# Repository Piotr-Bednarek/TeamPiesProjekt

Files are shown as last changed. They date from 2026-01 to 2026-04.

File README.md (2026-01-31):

<div align="center">

# Ball on Beam

</div>

## O projekcie

Celem projektu było stworzenie systemu automatycznego balansowania kulki na belce z wykorzystaniem sterowania automatycznego. Wykorzystano:

- **Regulator PID**
- **Czujnik odległości** VL53L0X
- **Serwomechanizm** do pochylania belki
- **Aplikację desktopową** do wizualizacji i strojenia parametrów

## Konstrukcja oraz aplikacja desktopowa

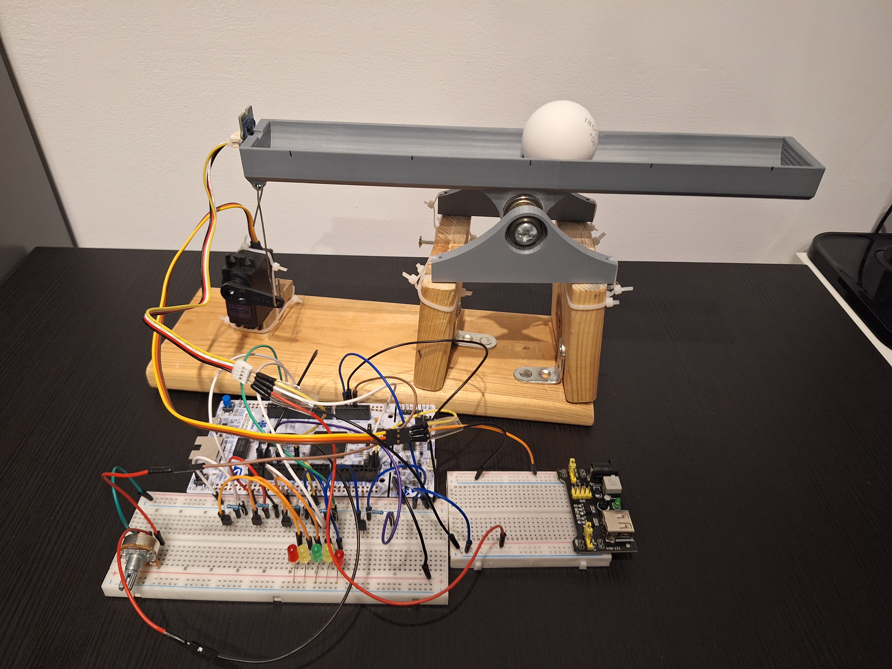
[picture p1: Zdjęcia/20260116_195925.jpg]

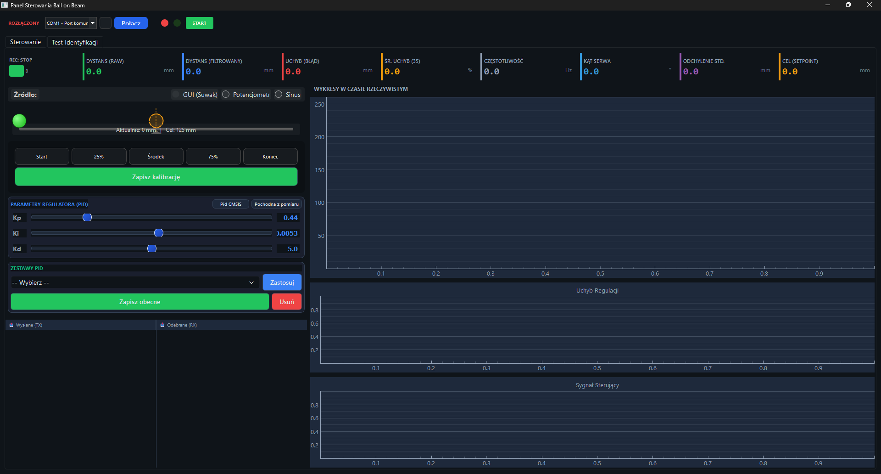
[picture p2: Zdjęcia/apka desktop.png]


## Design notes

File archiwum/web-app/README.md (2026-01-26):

# Aplikacja Webowa - STM32 Control

Nowoczesna aplikacja webowa napisana w React (Vite) do sterowania i wizualizacji danych z urządzenia STM32. Zastępuje poprzednią wersję desktopową (Python/Tkinter).

## Funkcje

-   **Połączenie Serial (Web Serial API)**: Bezpośrednie połączenie z portem COM z przeglądarki.
-   **Wizualizacja Real-time**: Wykresy odległości, błedu i sterowania.
-   **Panel Sterowania**: Zmiana parametrów PID i Setpoint na żywo.
-   **Terminal**: Podgląd logów TX/RX.
-   **Nowoczesny UI**: Ciemny motyw, responsywny layout.

## Uruchomienie

1. Zainstaluj zależności:
    ```bash
    npm install
    ```
2. Uruchom serwer developerski:
    ```bash
    npm run dev
    ```
3. Otwórz w przeglądarce (np. Chrome/Edge) adres wyświetlony w terminalu (zazwyczaj `http://localhost:5173`).

## Użycie

1. Kliknij **Connect Device** w prawym górnym rogu.
2. Wybierz port COM urządzenia STM32 z listy.
3. Dane zaczną pojawiać się na wykresach automatycznie.
4. Użyj suwaków by zmieniać `Setpoint` lub parametry `PID`.

**Uwaga**: Upewnij się, że inne aplikacje (np. stara aplikacja Python) nie blokują portu przed połączeniem.

-   [@vitejs/plugin-react-swc](https://github.com/vitejs/vite-plugin-react/blob/main/packages/plugin-react-swc) uses [SWC](https://swc.rs/) for Fast Refresh

## React Compiler

The React Compiler is not enabled on this template because of its impact on dev & build performances. To add it, see [this documentation](https://react.dev/learn/react-compiler/installation).

## Expanding the ESLint configuration

If you are developing a production application, we recommend using TypeScript with type-aware lint rules enabled. Check out the [TS template](https://github.com/vitejs/vite/tree/main/packages/create-vite/template-react-ts) for information on how to integrate TypeScript and [`typescript-eslint`](https://typescript-eslint.io) in your project.

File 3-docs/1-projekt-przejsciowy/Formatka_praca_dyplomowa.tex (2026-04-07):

% Preambuła: definicja klasy dokumentu i lista potrzebnych pakietów ///////////////////////////////////////////////////////////////////////////////////////////////////////

\documentclass[12pt, a4paper]{report} % rozmiar czcionki, klasa dokumentu
\usepackage[left=2.5cm, right=2.5cm, top=3.5cm, bottom=3.5cm]{geometry} % ustawienia marginesów
\usepackage{amsmath} % przydatne przy pisaniu wzorów i symboli matematycznych
\usepackage{amssymb} % j.w.
\usepackage{amsthm} % j.w.
\usepackage{polski} % język polski i skład tekstu zgodnie z polskimi zasadami typografii
\usepackage[T1]{fontenc} % polskie fonty w formacie wektorowym
\usepackage[utf8]{inputenc} % j.w.
\usepackage{enumerate} % konfiguracja wyglądu wypunktowań (i) (ii) A) B) 1) 2) etc.
\usepackage[pdftex]{graphicx} % umieszczanie grafiki w pracy (w tym również w formacie wektorowym PDF)
\usepackage{indentfirst} % wcięcie pierwszego akapitu
\usepackage{booktabs} % do rysowania eleganckich tabel
\usepackage{color} % kolor w LaTeXu
\usepackage{pgfplots} % rysowanie wykresów i grafiki wektorowej
\pgfplotsset{compat=1.18}
\usepackage{titlesec} % zmiana wyglądu tytułów rozdziałów (czcionka, odległości między wierszami tytułów etc.)
\usepackage[position=t,justification=centering, singlelinecheck=off]{subfig} % pozwala umieszczać rysunki obok siebie; etykiety (a) (b) etc. nad rysunkiem i wycentrowane
\usepackage{fancyhdr} % formatowanie nagłówka, stopki i żywej paginy
\usepackage{microtype} % optymalne (wizualnie) odstępy między znakami - poprawia czytelność tekstu
\usepackage[pdftex]{hyperref} % tworzenie połączeń hipertekstowych (odnośników)
\usepackage{lmodern}
\usepackage{float}    % umożliwia [H] dla figur
\usepackage{caption}  % formatowanie podpisów
\usepackage{listings} % listingi kodu źródłowego
\usepackage{xcolor}   % kolory dla listingów

% Kolory i style listingów kodu
\definecolor{codegreen}{rgb}{0,0.6,0}
\definecolor{codegray}{rgb}{0.5,0.5,0.5}
\definecolor{codepurple}{rgb}{0.58,0,0.82}
\definecolor{backcolour}{rgb}{0.95,0.95,0.92}
\definecolor{codeblue}{rgb}{0,0,0.7}

\lstdefinestyle{cstyle}{
    backgroundcolor=\color{backcolour},
    commentstyle=\color{codegreen},
    keywordstyle=\color{codeblue}\bfseries,
    numberstyle=\tiny\color{codegray},
    stringstyle=\color{codepurple},
    basicstyle=\ttfamily\footnotesize,
    breaklines=true,
    captionpos=b,
    keepspaces=true,
    numbers=left,
    numbersep=5pt,
    showstringspaces=false,
    tabsize=2,
    language=C,
    frame=single,
    rulecolor=\color{codegray},
    literate={ą}{{\k{a}}}1 {ć}{{\'c}}1 {ę}{{\k{e}}}1 {ł}{{\l{}}}1
             {ń}{{\'n}}1 {ó}{{\'o}}1 {ś}{{\'s}}1 {ź}{{\'z}}1 {ż}{{\.z}}1
             {Ą}{{\k{A}}}1 {Ć}{{\'C}}1 {Ę}{{\k{E}}}1 {Ł}{{\L{}}}1
             {Ń}{{\'N}}1 {Ó}{{\'O}}1 {Ś}{{\'S}}1 {Ź}{{\'Z}}1 {Ż}{{\.Z}}1
}

\lstdefinestyle{pythonstyle}{
    backgroundcolor=\color{backcolour},
    commentstyle=\color{codegreen},
    keywordstyle=\color{codeblue}\bfseries,
    numberstyle=\tiny\color{codegray},
    stringstyle=\color{codepurple},
    basicstyle=\ttfamily\footnotesize,
    breaklines=true,
    captionpos=b,
    keepspaces=true,
    numbers=left,
    numbersep=5pt,
    showstringspaces=false,
    tabsize=2,
    language=Python,
    frame=single,
    rulecolor=\color{codegray},
    literate={ą}{{\k{a}}}1 {ć}{{\'c}}1 {ę}{{\k{e}}}1 {ł}{{\l{}}}1
             {ń}{{\'n}}1 {ó}{{\'o}}1 {ś}{{\'s}}1 {ź}{{\'z}}1 {ż}{{\.z}}1
             {Ą}{{\k{A}}}1 {Ć}{{\'C}}1 {Ę}{{\k{E}}}1 {Ł}{{\L{}}}1
             {Ń}{{\'N}}1 {Ó}{{\'O}}1 {Ś}{{\'S}}1 {Ź}{{\'Z}}1 {Ż}{{\.Z}}1
}

% Konfiguracja nagłówka, stopki (w tym wyglądu i sposobu numeracji stron) i wyglądu tytułów głównych rozdziałów ///////////////////////////////////////////////

\pagestyle{fancy}
\cfoot{\thepage}
\fancyhead{} % czyści wszystkie pola w nagłówku
\fancyhead[RO,LE]{\textit {\textsl{Projekt i budowa układu regulacji dla układu Ball on Beam} \ldots}} % tekst w nagłówku
\fancyfoot{} % czyści wszystkie pola w stopce
\fancyfoot[C]{\thepage} % numery stron w stopce; wycentrowane

\titleformat{\chapter}[display]
  {\normalfont\Large\raggedleft}
  {\MakeUppercase{\chaptertitlename}
    \rlap{ \resizebox{!}{1.5cm}{\thechapter} \rule{5cm}{1.5cm}}}
  {10pt}{\Huge}
\titlespacing*{\chapter}{0pt}{30pt}{50pt} % odstępy w tytule głównym

% Początek dokumenty ///////////////////////////////////////////////////////////////////////////////////////////////////////////////////////////////////////////////////////////////
\begin{document}

  % Strona tytułowa
\begin{titlepage}

\vspace*{-2cm} % odstęp pionowy

\begin{center} % wypośrodkuj
\Large \textbf{POLITECHNIKA POZNAŃSKA}\\[1mm]
\Large {WYDZIAŁ AUTOMATYKI, ROBOTYKI I ELEKTROTECHNIKI}\\[1mm]
\begin{large}
Instytut Robotyki i Inteligencji Maszynowej\\[1mm]
Zakład Automatyki i Optymalizacji\\[1cm]
\end{large}
\end{center}

\begin{center}

\end{center}

\vspace{1cm}

\begin{center}
\Large \textbf {Jan Andrzejewski \\ Mateusz Banaszak \\ Piotr Bednarek}
\end{center}

\vspace{1cm}

\begin{center}
\Large \textbf{\textit{PROJEKT I BUDOWA UKŁADU REGULACJI DLA UKŁADU BALL ON BEAM}}
\end{center}

\vspace{3cm}
\hfill
\textbf {Promotor}: dr inż. Jacek Michalski

\vspace{2cm}

 \hspace*{-1cm}
\begin{minipage}{7cm}
\centering
Pracę przyjmuję i akceptuję\\

\vspace{0.5cm}

................................................\\

\textit{\footnotesize data i podpis opiekuna pracy}
\end{minipage}

\vspace{2.5cm}

\begin{center}
Poznań, \the\year
\end{center}

  % Pusta strona  (w tym miejscu karta tematu z Dziekanatu) \\\\\\\\\\\\\\\\\\\\\\\\\\\\\\\\\\\\\\\\\\\\\\\\\\\\\\\\\\\\\\\\\\\\\\\\\\\\\\\\\\\\\\\\\\\\\\\\\\\\\\\\\\\\\\\\\\
\newpage\null\thispagestyle{empty}\newpage

 % Streszczenie \\\\\\\\\\\\\\\\\\\\\\\\\\\\\\\\\\\\\\\\\\\\\\\\\\\\\\\\\\\\\\\\\\\\\\\\\\\\\\\\\\\\\\\\\\\\\\\\\\\\\\\\\\\\\\\\\\\\\\\\\\\\\\\\\\\\\\\\\\\\\\\\\\\\\\\\\\\\\\\\\\\\\\\
    \newpage\thispagestyle{empty}
    \vspace*{2\baselineskip}
    \begin{center}
	{\large\bfseries Streszczenie}\par\bigskip
    \end{center}

    {\itshape
    Praca przedstawia projekt i~budowę autonomicznego stanowiska do sterowania
    pozycją kulki na belce (\textit{ball and beam}) z~wykorzystaniem mikrokontrolera
    STM32F767ZI.
    Opisano budowę mechaniczną stanowiska, zastosowane peryferia (serwomechanek
    MG946R, czujnik odległości VL53L0X, rząd diod LED, potencjometr) oraz
    architekturę oprogramowania opartą na systemie FreeRTOS.
    Wyprowadzono model matematyczny układu i~zaprojektowano dwa regulatory:
    klasyczny PID z~anti-windup oraz optymalny LQR w~przestrzeni stanów.
    Aplikacja nadzorcza napisana w~Pythonie (PySide6) umożliwia wizualizację
    sygnałów w~czasie rzeczywistym, zapis danych do pliku CSV oraz zdalne
    strojenie regulatora.
    Przeprowadzono weryfikację eksperymentalną i~potwierdzono spełnienie
    wszystkich wymagań projektowych.
    }
    \vspace*{1\baselineskip}

    \noindent{\bf Słowa kluczowe}: {\itshape regulacja automatyczna, kulka na belce,
    STM32, PID, LQR, FreeRTOS, VL53L0X.}
    \par
    \vspace{4\baselineskip}

  % Abstract \\\\\\\\\\\\\\\\\\\\\\\\\\\\\\\\\\\\\\\\\\\\\\\\\\\\\\\\\\\\\\\\\\\\\\\\\\\\\\\\\\\\\\\\\\\\\\\\\\\\\\\\\\\\\\\\\\\\\\\\\\\\\\\\\\\\\\\\\\\\\\\\\\\\\\\\\\\\\\\\\\\\\\\\\\\
    \begin{center}
	{\large\bfseries Abstract}\par\bigskip
    \end{center}
    \noindent{\bf Title}: {\itshape Design and Construction of a Control System for the Ball and Beam System.}\par
    \vspace*{1\baselineskip}
    {\itshape
    This thesis presents the design and construction of an autonomous ball-and-beam
    control system based on the STM32F767ZI microcontroller.
    The mechanical setup, hardware peripherals (MG946R servo, VL53L0X time-of-flight
    sensor, LED bar, potentiometer), and FreeRTOS-based software architecture are
    described.
    A mathematical model of the plant is derived and two controllers are designed:
    a classical PID with anti-windup and an optimal LQR state-feedback controller.
    A supervisory desktop application (Python/PySide6) provides real-time signal
    visualisation, CSV data logging, and remote parameter tuning.
    Experimental verification confirms that all project requirements are satisfied.
    }
    \vspace*{1\baselineskip}

    \noindent{\bf Key words}: {\itshape automatic control, ball and beam, STM32, PID,
    LQR, FreeRTOS, VL53L0X.}

\end{titlepage}

  % Spis treści ]\\\\\\\\\\\\\\\\\\\\\\\\\\\\\\\\\\\\\\\\\\\\\\\\\\\\\\\\\\\\\\\\\\\\\\\\\\\\\\\\\\\\\\\\\\\\\\\\\\\\\\\\\\\\\\\\\\\\\\\\\\\\\\\\\\\\\\\\\\\\\\\\\\\\\\\\\\\\\\\\\\\\\\\\\

\tableofcontents % wstawia spis treści

 % Główna część pracy \\\\\\\\\\\\\\\\\\\\\\\\\\\\\\\\\\\\\\\\\\\\\\\\\\\\\\\\\\\\\\\\\\\\\\\\\\\\\\\\\\\\\\\\\\\\\\\\\\\\\\\\\\\\\\\\\\\\\\\\\\\\\\\\\\\\\\\\\\\\\\\\\\\

% ROZDZIAŁ 1 _________________________________________________________________________________________________________________
\input{1-wprowadzenie/1-wprowadzenie}

% ROZDZIAŁ 2 _________________________________________________________________________________________________________________
\input{2-budowa-stanowiska-i-oprogramowanie/2-budowa-stanowiska-i-oprogramowanie}

% ROZDZIAŁ 3 _________________________________________________________________________________________________________________
\input{3-model-matematyczny-i-projekt-regulacji/3-model-matematyczny-i-projekt-regulacji}

% ROZDZIAŁ 4 _________________________________________________________________________________________________________________
\input{4-wyniki-eksperymentalne/4-wyniki-eksperymentalne}

% ROZDZIAŁ 5 _________________________________________________________________________________________________________________
\input{5-podsumowanie-i-wnioski/5-podsumowanie-i-wnioski}

% BIBLIOGRAFIA ___________________________________________________________________________________________________________
\bibliographystyle{unsrt} % kolejność cytowania w tekście
\bibliography{bibliografia}

\listoffigures
\appendix

\end{document}

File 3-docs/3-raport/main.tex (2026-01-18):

\documentclass[11pt]{article}

\pdfobjcompresslevel=3    % compress PDF objects
\pdfcompresslevel=9       % compress streams more (0..9)
\pdfminorversion=4

\usepackage[utf8]{inputenc} % remove if using XeLaTeX or LuaLaTeX
\usepackage[T1]{fontenc}
\usepackage{polski}[babel]

% Layout & graphics
\usepackage[a4paper, total={7.5in, 9in}]{geometry}
\usepackage{graphicx}
\usepackage{wrapfig}              % images
\usepackage[dvipsnames,table]{xcolor} % single xcolor invocation (keeps table option)

% Math & symbols
\usepackage{amsmath}
\usepackage{amssymb}
\usepackage{gensymb}

% Typography & layout helpers
\usepackage{microtype}
\usepackage{float}                 % [H] placement
\usepackage{caption}
\usepackage{subcaption}            % modern subfigure support (do NOT load subfig)
\usepackage{multirow}
\usepackage{titlesec}

\usepackage{lmodern}
\usepackage{listings}
\usepackage{xcolor}

\geometry{margin=2.5cm}

% Kolory dla listingow kodu
\definecolor{codegreen}{rgb}{0,0.6,0}
\definecolor{codegray}{rgb}{0.5,0.5,0.5}
\definecolor{codepurple}{rgb}{0.58,0,0.82}
\definecolor{backcolour}{rgb}{0.95,0.95,0.92}
\definecolor{codeblue}{rgb}{0,0,0.7}

\definecolor{xppblue}{RGB}{37, 150, 190}

% Styl dla kodu C
\lstdefinestyle{cstyle}{
    backgroundcolor=\color{backcolour},   
    commentstyle=\color{codegreen},
    keywordstyle=\color{codeblue}\bfseries,
    numberstyle=\tiny\color{codegray},
    stringstyle=\color{codepurple},
    basicstyle=\ttfamily\footnotesize,
    breakatwhitespace=false,         
    breaklines=true,                 
    captionpos=b,                    
    keepspaces=true,                 
    numbers=left,                    
    numbersep=5pt,                  
    showspaces=false,                
    showstringspaces=false,
    showtabs=false,                  
    tabsize=2,
    language=C,
    frame=single,
    rulecolor=\color{codegray},
    literate={ą}{{\k{a}}}1 {ć}{{\'c}}1 {ę}{{\k{e}}}1 {ł}{{\l{}}}1 {ń}{{\'n}}1 {ó}{{\'o}}1 {ś}{{\'s}}1 {ź}{{\'z}}1 {ż}{{\.z}}1
             {Ą}{{\k{A}}}1 {Ć}{{\'C}}1 {Ę}{{\k{E}}}1 {Ł}{{\L{}}}1 {Ń}{{\'N}}1 {Ó}{{\'O}}1 {Ś}{{\'S}}1 {Ź}{{\'Z}}1 {Ż}{{\.Z}}1
}

% Styl dla kodu Python
\lstdefinestyle{pythonstyle}{
    backgroundcolor=\color{backcolour},   
    commentstyle=\color{codegreen},
    keywordstyle=\color{codeblue}\bfseries,
    numberstyle=\tiny\color{codegray},
    stringstyle=\color{codepurple},
    basicstyle=\ttfamily\footnotesize,
    breakatwhitespace=false,         
    breaklines=true,                 
    captionpos=b,                    
    keepspaces=true,                 
    numbers=left,                    
    numbersep=5pt,                  
    showspaces=false,                
    showstringspaces=false,
    showtabs=false,                  
    tabsize=2,
    language=Python,
    frame=single,
    rulecolor=\color{codegray},
    literate={ą}{{\k{a}}}1 {ć}{{\'c}}1 {ę}{{\k{e}}}1 {ł}{{\l{}}}1 {ń}{{\'n}}1 {ó}{{\'o}}1 {ś}{{\'s}}1 {ź}{{\'z}}1 {ż}{{\.z}}1
             {Ą}{{\k{A}}}1 {Ć}{{\'C}}1 {Ę}{{\k{E}}}1 {Ł}{{\L{}}}1 {Ń}{{\'N}}1 {Ó}{{\'O}}1 {Ś}{{\'S}}1 {Ź}{{\'Z}}1 {Ż}{{\.Z}}1
}

\lstset{style=cstyle}

\begin{document}

\begin
{table}[H]
\centering
\begin
{tabular}{|p{4cm}|p{8cm}|p{2cm}|}
\hline
\multicolumn{2}{|c|}{\cellcolor{xppblue}\textcolor[rgb]{1,1,1}{Politechnika Poznańska}}  & \multicolumn{1}{c|}{\multirow{3}{*}{\resizebox{14mm}{!}{}}}\\
\multicolumn{2}{|c|}{\cellcolor{xppblue}\textcolor[rgb]{1,1,1}{Wydział Automatyki, Robotyki i Elektrotechniki}} & \\
\multicolumn{2}{|c|}{\cellcolor{xppblue}\textcolor[rgb]{1,1,1}{Instytut Robotyki i Inteligencji Maszynowej}} & \\
\hline
\multicolumn{1}{|c|}{AiR Sem 5} & \multicolumn{1}{c|}{Systemy mikroprocesorowe} & \multicolumn{1}{c|}{2025/26 (s.zim.)} \\
\hline
Jan Andrzejewski \par Mateusz Banaszak \par Piotr Bednarek & \textbf{Raport z projektu zaliczeniowego} \par Ball on Beam & Data wyk.:\par 18.01.2026\\
\hline
Grupa środa 13:30  & &  \\
\hline
\end{tabular}
\end{table}

\tableofcontents
\newpage

\section{Wprowadzenie}
\subsection{Zakres i cel projektu}

Za cel projektu obrano zbudowanie stanowiska służacego do sterowania obiektem dynamiczym "Ball on beam". Za cel przy implementacji zostało przyjęte spełnienie dodatkowych wymogów projektowych opisanych w następnym rozdziale. 

\begin{figure}[H]
    \centering
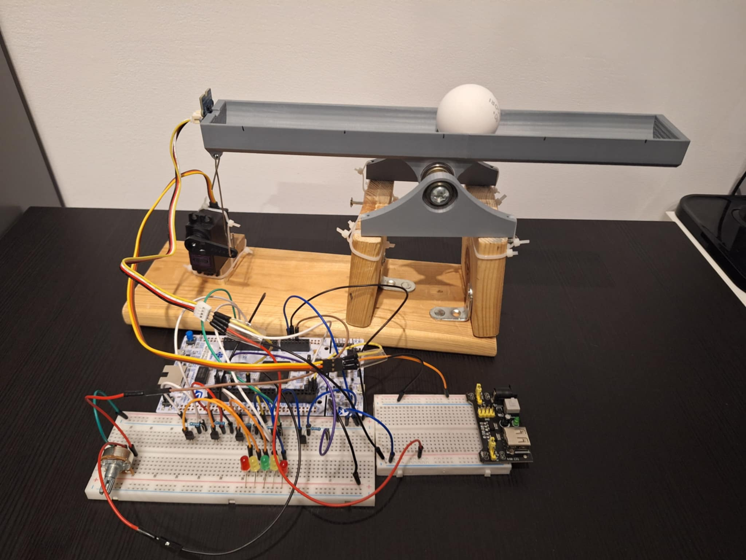
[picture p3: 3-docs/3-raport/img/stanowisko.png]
    
    \caption{Stanowisko}
\end{figure}

\begin{figure}[H]
    \centering
    
    \caption{Aplikacja desktopowa}
\end{figure}

\subsection{Wykorzystane elementy}

\begin{itemize}
    \item STM Nucleo F767ZI
    \item Servo TowerPro MG946R
    \item Grove - VL53LOX Timeof Flight I2C
    \item Diody LED - 1x zielona, 2x czerwona, 2x żółta 
    \item 5x tranzystory npn pn2222
    \item 5x rezystory 2k$\Omega$
    \item Potencjometr 
    \item Zasilacz 5 V
\end{itemize}

%%%%%%%%%%%%%%%%%%%%%%%%%%%%%%%%%%%%%%%%%%%%%%%%%%%%%%%%%%%%%%%%%%%%%%%%%%%%%%%
\section{Wymagania projektowe}
%%%%%%%%%%%%%%%%%%%%%%%%%%%%%%%%%%%%%%%%%%%%%%%%%%%%%%%%%%%%%%%%%%%%%%%%%%%%%%%

Poniżej przedstawiono wymagania projektowe, które spełnia projekt, wraz z fragmentami kodu dokumentującymi ich implementację.

%------------------------------------------------------------------------------
\subsection{Pomiar zmiennej regulowanej ze stałym okresem próbkowania}
%------------------------------------------------------------------------------

System dokonuje pomiaru regulowanej zmiennej (pozycji kulki) ze stałym okresem próbkowania zdefiniowanym jako \texttt{PID\_DT\_MS = 30ms}. Zapewnia to funkcja \texttt{osDelay()} systemu FreeRTOS wywołana na końcu pętli sterowania.

\begin{lstlisting}[caption={Stały okres próbkowania (main.h)}, style=cstyle]
// --- Global System Settings ---
#define PID_DT_MS          30
#define SETPOINT_DEFAULT   125.0f
#define BALL_RADIUS        20
#define AVG_ERR_SAMPLES    35
\end{lstlisting}

\begin{lstlisting}[caption={Implementacja stałego okresu w pętli sterowania (main.c)}, style=cstyle]
/* Infinite loop */
for (;;) {
    loop_counter++;
    
    // ... kod sterowania ...
    
    // Odczyt dystansu w trybie continuous
    distance = readRangeContinuousMillimeters(&distanceStr);
    
    // ... obliczenia PID ...
    
    osDelay(PID_DT_MS); // Loop delay - staly okres 30ms
}
\end{lstlisting}

%------------------------------------------------------------------------------
\subsection{Sterowanie w bezpiecznym zakresie zmian regulowanej zmiennej}
%------------------------------------------------------------------------------

System zapewnia bezpieczne sterowanie poprzez zdefiniowanie twardych limitów kąta serwa w pliku \texttt{main.h} oraz ich egzekwowanie w kodzie sterowania.

\begin{lstlisting}[caption={Definicje limitów bezpieczeństwa serwa (main.h)}, style=cstyle]
// --- Servo Configuration ---
#define SERVO_CENTER       100.0f
#define SERVO_MIN_LIMIT    60.0f
#define SERVO_MAX_LIMIT    140.0f
#define SERVO_ANGLE_DEADBAND 0.8f
\end{lstlisting}

\begin{lstlisting}[caption={Saturacja wyjścia PID (main.c)}, style=cstyle]
// Zabezpieczenie przed NaN (Not a Number)
if (isnan(pid_angle) || isinf(pid_angle)) {
    pid_angle = SERVO_CENTER;
}

if (pid_angle < SERVO_MIN_LIMIT)
    pid_angle = SERVO_MIN_LIMIT;
else if (pid_angle > SERVO_MAX_LIMIT)
    pid_angle = SERVO_MAX_LIMIT;

// Bezposrednie sterowanie serwem
volatile float smoothed_angle = pid_angle;
SetServoAngle(smoothed_angle);
\end{lstlisting}

\newpage

%------------------------------------------------------------------------------
\subsection{Uchyb ustalony na poziomie 5\% (i 1\%) zakresu regulacji}
%------------------------------------------------------------------------------

System oblicza średni błąd (rolling average) z ostatnich 35 próbek, co pozwala na monitorowanie uchybu ustalonego. Zakres regulacji wynosi 250 mm, więc 5\% = 12,5 mm, a 1\% = 2,5 mm.

Wartość średniego uchybu jest przesyłana przez UART i wyświetlana w czasie rzeczywistym w aplikacji desktopowej na panelu metryk oraz na wykresie. Umożliwia to bieżącą ocenę jakości regulacji bez konieczności analizy surowych danych.

\begin{lstlisting}[caption={Obliczenie uchybu z 35 (main.c)}, style=cstyle]
// --- Obliczanie Średniego Błędu (Rolling Average) ---
		float current_abs_err = (current_error < 0) ? -current_error : current_error;
		
		err_sum -= err_buffer[err_idx];       // Odejmij najstarszą próbkę
		err_buffer[err_idx] = current_abs_err; // Zapisz nową
		err_sum += current_abs_err;           // Dodaj nową próbkę
		
		err_idx++;
		if(err_idx >= AVG_ERR_SAMPLES) err_idx = 0;
		
		float avg_error = err_sum / AVG_ERR_SAMPLES;
\end{lstlisting}

%------------------------------------------------------------------------------
\subsection{Zadawanie wartości referencyjnej za pomocą komunikacji szeregowej lub urządzenia wejścia}
%------------------------------------------------------------------------------

Wartość referencyjna może być zadawana na dwa sposoby:
\begin{itemize}
    \item Przez komunikację szeregową UART (komenda \texttt{S:wartosc})
    \item Przez potencjometr podłączony do wejścia ADC (PA0)
\end{itemize}

\begin{lstlisting}[caption={Obsługa komendy setpointu przez UART (main.c)}, style=cstyle]
void StartDefaultTask(void const * argument) {
    for (;;) {
        // Obsluga komend UART
        if (cmd_received) {
            if (rx_buffer[0] == 'S' && rx_buffer[1] == ':') {
                g_setpoint = atof((char*) &rx_buffer[2]); // S:Setpoint
                if (g_setpoint < 0.0f)
                    g_setpoint = 0.0f;
                if (g_setpoint > 250.0f)
                    g_setpoint = 250.0f;
            }
            // ... inne komendy ...
            cmd_received = 0;
        }
        osDelay(5);
    }
}
\end{lstlisting}

\begin{lstlisting}[caption={Odczyt setpointu z potencjometru ADC (main.c)}, style=cstyle]
// --- Obsluga Potencjometru ---
HAL_ADC_Start(&hadc1);
if (HAL_ADC_PollForConversion(&hadc1, 10) == HAL_OK) {
    g_adc_raw = HAL_ADC_GetValue(&hadc1);
    float pot_setpoint = (float)g_adc_raw * 0.070818f; 
    g_pot_setpoint = pot_setpoint; 
    
    // Jeśli tryb Analog, nadpisz setpoint
    if (control_mode == 1) {
        // Lekki filtr na setpoint z potencjometru
        static float pot_ema = 0.0f;
        if (pot_ema == 0.0f) pot_ema = pot_setpoint;
        pot_ema = 0.1f * pot_setpoint + 0.9f * pot_ema;
        g_setpoint = pot_ema;
    }
}
HAL_ADC_Stop(&hadc1);
\end{lstlisting}

%------------------------------------------------------------------------------
\subsection{Podgląd sygnałów przez komunikację szeregową}
%------------------------------------------------------------------------------

System wysyła dane pomiarowe przez UART w formacie tekstowym z sumą kontrolną CRC-8. Dane zawierają: dystans surowy (D), setpoint (Z), kąt serwa (A), dystans filtrowany (F), błąd (E), średni błąd (V) oraz status sensora (S).

\begin{lstlisting}[caption={Wysyłanie danych przez UART z CRC (main.c)}, style=cstyle]
char data_buffer[64];
// D:Dist (raw); A:Angle; F:Filtered; E:Error; V:AvgError; S:Status; Z:Setpoint
int len = sprintf(data_buffer, "D:%d;Z:%d;A:%d;F:%d;E:%d;V:%d;S:%d", 
    (int)raw_distance, (int)g_setpoint, (int)smoothed_angle, 
    (int)filtered_dist, (int)current_error, (int)avg_error, 
    distanceStr.rangeStatus);

uint8_t out_crc = CalculateCRC8(data_buffer, len);

sprintf(msg, "%s;C:%02X\r\n", data_buffer, out_crc);
static uint8_t u_throttle = 0;
if (++u_throttle >= 2) {
    u_throttle = 0;
    HAL_UART_Transmit(&huart3, (uint8_t*) msg, strlen(msg), 10);
}
\end{lstlisting}

%------------------------------------------------------------------------------
\subsection{Podział kodu na moduły i dokumentacja Doxygen}
%------------------------------------------------------------------------------

Kod źródłowy jest podzielony na osobne moduły o jasno zdefiniowanych funkcjonalnościach. Każdy moduł posiada dokumentację zgodną ze standardem Doxygen.

\textbf{Struktura modułów STM32:}
\begin{itemize}
    \item \texttt{main.c/h} -- główna aplikacja, konfiguracja peryferiów
    \item \texttt{pid.c/h} -- wrapper na CMSIS DSP PID
    \item \texttt{servo\_pid.c/h} -- własna implementacja PID z Anti-Windup
    \item \texttt{filters.c/h} -- filtry cyfrowe (Mediana, EMA, 1-Euro)
    \item \texttt{crc8.c/h} -- obliczanie sumy kontrolnej CRC-8
    \item \texttt{leds.c/h} -- wizualizacja błędu na LEDach
    \item \texttt{calibration.c/h} -- kalibracja sensora
\end{itemize}

\begin{lstlisting}[caption={Przykład dokumentacji Doxygen (pid.c)}, style=cstyle]
/**
 ******************************************************************************
 * @file    pid.c
 * @author  Piotr Bednarek Jan Andrzejewski Mateusz Banaszak
 * @date    Jan 8, 2026
 * @brief   Wrapper na biblioteke CMSIS DSP PID.
 *
 * Plik zawiera funkcje inicjalizujace i obslugujace regulator PID
 * z wykorzystaniem zoptymalizowanej biblioteki matematycznej ARM (CMSIS DSP).
 ******************************************************************************
 */

/**
 * @brief Inicjalizuje regulator PID.
 *        Ustawia wspolczynniki wzmocnienia oraz limity wyjscia (nasycenie).
 *        Wywoluje arm_pid_init_f32 aby zresetowac stan wewnetrzny algorytmu.
 * @param pid Wskaznik do struktury PID_Controller_t.
 * @param Kp Wzmocnienie proporcjonalne.
 * @param Ki Wzmocnienie calkujace.
 * @param Kd Wzmocnienie rozniczkujace.
 * @param min_out Dolny limit wyjscia.
 * @param max_out Gorny limit wyjscia.
 */
void PID_Init(PID_Controller_t *pid, float Kp, float Ki, float Kd, 
              float min_out, float max_out) {
    // ...
}
\end{lstlisting}

%------------------------------------------------------------------------------
\subsection{Wykorzystanie systemu kontroli wersji}
%------------------------------------------------------------------------------

Projekt wykorzystuje system kontroli wersji Git. Repozytorium znajduje sie w katalogu glownym projektu (\texttt{.git/}).

%------------------------------------------------------------------------------
\subsection{Dedykowana aplikacja desktopowa (GUI)}
%------------------------------------------------------------------------------

Aplikacja desktopowa została napisana w języku Python z wykorzystaniem frameworka PySide6 (Qt). Umożliwia ona:
\begin{itemize}
    \item Połączenie z mikrokontrolerem przez port szeregowy
    \item Wizualizację sygnałów w czasie rzeczywistym (wykresy PyQtGraph)
    \item Wybór trybu (UI, sinus, śledzenie trajektorii) i zadawanie sygnału referencyjnego 
    \item Zadawanie wartości parametrów PID
    \item Nagrywanie i eksport sygnałów do CSV
    \item Sterowanie trybem pracy regulatora (Start/Stop)
\end{itemize}

\begin{lstlisting}[caption={Główna klasa aplikacji GUI (app.py)}, style=pythonstyle]
from PySide6.QtWidgets import QMainWindow, QWidget, QVBoxLayout, QHBoxLayout
from serial_manager import SerialManager
from widgets.metrics_panel import MetricsPanel
from widgets.control_panel import ControlPanel
from widgets.charts_panel import ChartsPanel
from widgets.terminal import Terminal

class MainWindow(QMainWindow):
    def __init__(self):
        super().__init__()
        
        self.setWindowTitle("Panel Sterowania Ball on Beam")
        self.resize(1280, 800)
        
        # --- Managers ---
        self.serial = SerialManager()
        self.data_history = []
        
        # --- Recording State ---
        self.is_recording = False
        self.recording_data = []
        
        # ... konfiguracja UI ...
\end{lstlisting}

\begin{lstlisting}[caption={Manager komunikacji szeregowej (serial\_manager.py)}, style=pythonstyle]
class SerialManager(QObject):
    """
    High-level manager for Serial communication. 
    Handles Thread management, Parsing, and Signal emission.
    """
    # Signals for UI
    connected = Signal(bool)
    rx_log = Signal(str, str)  # msg, type (info/error/success)
    tx_log = Signal(str)
    new_data = Signal(dict)    # Parsed data object
    ports_listed = Signal(list)
    
    def send_setpoint(self, val):
        self.send_command(f"S:{val:.1f}")
        
    def send_pid(self, kp, ki, kd):
        self.send_pid_p(kp)
        QThread.msleep(500)
        self.send_pid_i(ki)
        QThread.msleep(500)
        self.send_pid_d(kd)
\end{lstlisting}

%------------------------------------------------------------------------------
\subsection{Skrypty do logowania sygnałów}
%------------------------------------------------------------------------------

Aplikacja desktopowa posiada wbudowany mechanizm nagrywania danych pomiarowych do plików CSV z możliwością eksportu.

\begin{lstlisting}[caption={Funkcja zapisu nagrania do CSV (app.py)}, style=pythonstyle]
def _save_recording(self):
    # Generate default filename with timestamp
    timestamp = datetime.now().strftime("%Y%m%d_%H%M%S")
    default_filename = f"nagranie_{timestamp}.csv"
    
    # Open file dialog
    filepath, _ = QFileDialog.getSaveFileName(
        self,
        "Zapisz nagranie",
        default_filename,
        "CSV Files (*.csv);;All Files (*)"
    )
    
    if filepath:
        try:
            with open(filepath, 'w', newline='', encoding='utf-8') as f:
                fieldnames = ['time', 'distance', 'filtered', 
                              'setpoint', 'error', 'control']
                writer = csv.DictWriter(f, fieldnames=fieldnames)
                writer.writeheader()
                writer.writerows(self.recording_data)
        except Exception as e:
            self.terminal.append_rx(f"Blad zapisu: {e}", "error")
\end{lstlisting}

%------------------------------------------------------------------------------
\subsection{Dodatkowe urządzenie wyjścia -- wyświetlacz LED}
%------------------------------------------------------------------------------

System posiada 5 diod LED (PE2--PE6) wizualizujących aktualny uchyb regulacji:
\begin{itemize}
    \item LED zielona (PE4) -- błąd w zakresie $\pm$1\% (2,5 mm)
    \item LEDy żółte (PE3, PE5) -- błąd w zakresie $\pm$5\% (12,5 mm)
    \item LEDy czerwone (PE2, PE6) -- błąd większy niż $\pm$5\%
\end{itemize}

\begin{lstlisting}[caption={Definicje pinow LED (main.h)}, style=cstyle]
// --- LED Error Bar ---
#define LED_ERR_PORT      GPIOE
#define LED_ERR_1_Pin     GPIO_PIN_2 //PE2
#define LED_ERR_2_Pin     GPIO_PIN_3 //PE3
#define LED_ERR_3_Pin     GPIO_PIN_4 //PE4
#define LED_ERR_4_Pin     GPIO_PIN_5 //PE5
#define LED_ERR_5_Pin     GPIO_PIN_6 //PE6
\end{lstlisting}

\begin{lstlisting}[caption={Update stanu LED (leds.c)}, style=cstyle]
void UpdateErrorLEDs_5LED(float error) {
	// Wyłącz wszystkie LEDy (PE2..PE6)
	HAL_GPIO_WritePin(GPIOE, LED_ERR_1_Pin | LED_ERR_2_Pin | LED_ERR_3_Pin | 
	                         LED_ERR_4_Pin | LED_ERR_5_Pin, GPIO_PIN_RESET);
	
	// Progi: 
	// 1% z 250mm = 2.5mm
	// 5% z 250mm = 12.5mm
	float limit_green = 2.5f;
	float limit_yellow = 12.5f;
	
	if (error < -limit_yellow) {
		// Duży ujemny -> Czerwona (PE2 - LED_ERR_1)
		HAL_GPIO_WritePin(GPIOE, LED_ERR_1_Pin, GPIO_PIN_SET);
	} else if (error < -limit_green) {
		// Średni ujemny -> Żółta (PE3 - LED_ERR_2)
		HAL_GPIO_WritePin(GPIOE, LED_ERR_2_Pin, GPIO_PIN_SET);
	} else if (error <= limit_green) { 
		// Mały błąd (+/- 2.5mm) -> Zielona (PE4 - LED_ERR_3)
		HAL_GPIO_WritePin(GPIOE, LED_ERR_3_Pin, GPIO_PIN_SET);
	} else if (error <= limit_yellow) {
		// Średni dodatni -> Żółta (PE5 - LED_ERR_4)
		HAL_GPIO_WritePin(GPIOE, LED_ERR_4_Pin, GPIO_PIN_SET);
	} else {
		// Duży dodatni -> Czerwona (PE6 - LED_ERR_5)
		HAL_GPIO_WritePin(GPIOE, LED_ERR_5_Pin, GPIO_PIN_SET);
	}
}
\end{lstlisting}

\begin{figure}[H]
    \centering
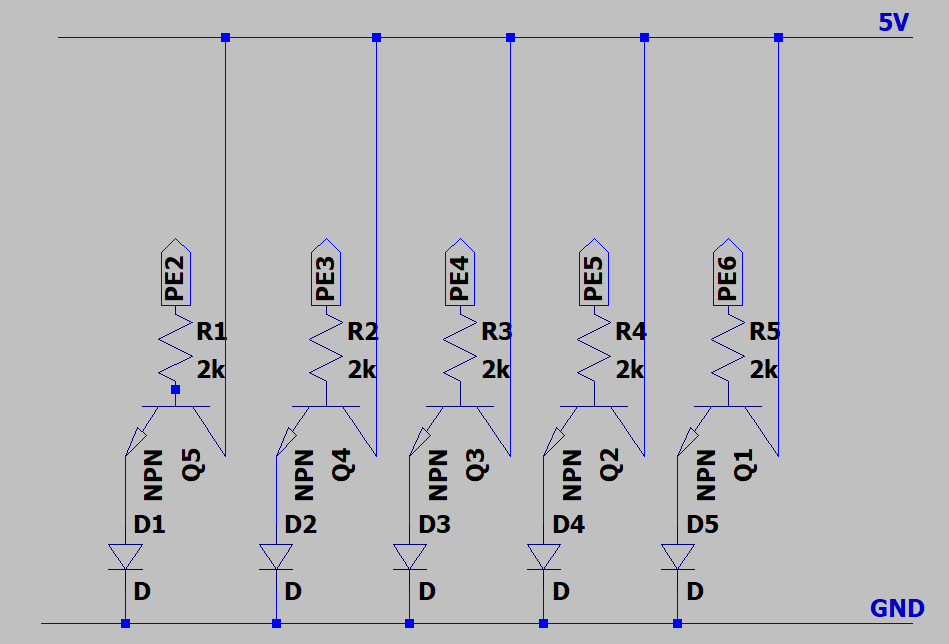
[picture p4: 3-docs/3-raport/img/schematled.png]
    
    \caption{Schemat połączenia LED}
\end{figure}

%------------------------------------------------------------------------------
\subsection{Dodatkowe urządzenie wejścia -- potencjometr}
%------------------------------------------------------------------------------

System wykorzystuje potencjometr podłączony do wejścia analogowego PA0 (ADC1\_CH0) do zadawania wartości referencyjnej w trybie analogowym.

\begin{lstlisting}[caption={Konfiguracja ADC dla potencjometru (main.c)}, style=cstyle]
static void MX_ADC1_Init(void) {
    ADC_ChannelConfTypeDef sConfig = {0};
    
    hadc1.Instance = ADC1;
    hadc1.Init.ClockPrescaler = ADC_CLOCK_SYNC_PCLK_DIV4;
    hadc1.Init.Resolution = ADC_RESOLUTION_12B;
    hadc1.Init.ScanConvMode = ADC_SCAN_DISABLE;
    hadc1.Init.ContinuousConvMode = DISABLE;
    // ...
    
    sConfig.Channel = ADC_CHANNEL_0;
    sConfig.Rank = ADC_REGULAR_RANK_1;
    sConfig.SamplingTime = ADC_SAMPLETIME_480CYCLES;
    HAL_ADC_ConfigChannel(&hadc1, &sConfig);
}
\end{lstlisting}

%------------------------------------------------------------------------------
\subsection{Protokół komunikacji z sumą kontrolną CRC-8}
%------------------------------------------------------------------------------

Komunikacja szeregowa wykorzystuje sumę kontrolną CRC-8 z wielomianem 0x07 dla zapewnienia integralności danych. Implementacja jest identyczna po stronie STM32 (C) i aplikacji desktopowej (Python).

\begin{lstlisting}[caption={Implementacja CRC-8 (crc8.c)}, style=cstyle]
/**
 * @brief Oblicza CRC-8 dla ciagu danych.
 *        Algorytm XOR z przesunieciami bitowymi.
 */
uint8_t CalculateCRC8(const char *data, int len) {
    uint8_t crc = 0x00;
    for (int i = 0; i < len; i++) {
        crc ^= data[i];
        for (uint8_t j = 0; j < 8; j++) {
            if (crc & 0x80)
                crc = (crc << 1) ^ 0x07;
            else
                crc <<= 1;
        }
    }
    return crc;
}
\end{lstlisting}

\begin{lstlisting}[caption={Implementacja CRC-8 w Pythonie (utils/crc8.py)}, style=pythonstyle]
def calculate_crc8(text: str) -> int:
    """
    Calculates 8-bit CRC for the given string using polynomial 0x07.
    Consistent with the STM32 implementation.
    """
    crc = 0x00
    if not text:
        return 0
        
    for char in text:
        byte = ord(char)
        crc ^= byte
        for _ in range(8):
            if crc & 0x80:
                crc = (crc << 1) ^ 0x07
            else:
                crc <<= 1
            crc &= 0xFF
            
    return crc
\end{lstlisting}

%------------------------------------------------------------------------------
\subsection{Wykorzystanie systemu czasu rzeczywistego FreeRTOS}
%------------------------------------------------------------------------------

System wykorzystuje FreeRTOS jako system operacyjny czasu rzeczywistego. Zdefiniowane sa dwa taski:
\begin{itemize}
    \item \texttt{ControlTask} (priorytet wysoki) -- petla sterowania PID
    \item \texttt{DefaultTask} (priorytet normalny) -- obsluga komend UART i LEDow
\end{itemize}

\begin{lstlisting}[caption={Tworzenie taskow FreeRTOS (main.c)}, style=cstyle]
/* Create the thread(s) */
/* definition and creation of defaultTask */
osThreadDef(defaultTask, StartDefaultTask, osPriorityNormal, 0, 256);
defaultTaskHandle = osThreadCreate(osThread(defaultTask), NULL);

/* definition and creation of ControlTask */
osThreadDef(ControlTask, StartControlTask, osPriorityHigh, 0, 1024);
ControlTaskHandle = osThreadCreate(osThread(ControlTask), NULL);

/* Start scheduler */
osKernelStart();
\end{lstlisting}

\begin{lstlisting}[caption={Task sterowania PID (main.c)}, style=cstyle]
/**
 * @brief Function implementing the ControlTask thread.
 * @param argument: Not used
 * @retval None
 */
void StartControlTask(void const * argument) {
    // Uruchomienie PWM dla serwa
    HAL_TIM_PWM_Start(&htim3, TIM_CHANNEL_1);
    
    // Inicjalizacja czujnika VL53L0X
    initVL53L0X(1, &hi2c1);
    startContinuous(0);
    
    // Inicjalizacja kontrolera PID
    PID_Init(&g_pid_ctrl, g_Kp, g_Ki, g_Kd, SERVO_MIN_LIMIT, SERVO_MAX_LIMIT);
    ServoPID_Init(&g_servo_pid);
    
    for (;;) {
        // Petla sterowania PID
        distance = readRangeContinuousMillimeters(&distanceStr);
        
        // ... filtrowanie i kalibracja ...
        
        // Obliczenie PID
        pid_output = ServoPID_Compute(&g_servo_pid, error, filtered_dist);
        SetServoAngle(pid_output);
        
        osDelay(PID_DT_MS);
    }
}
\end{lstlisting}

\begin{lstlisting}[caption={Konfiguracja FreeRTOS (freertos.c)}, style=cstyle]
/* Includes */
#include "FreeRTOS.h"
#include "task.h"
#include "main.h"

/* GetIdleTaskMemory prototype (linked to static allocation support) */
void vApplicationGetIdleTaskMemory(StaticTask_t **ppxIdleTaskTCBBuffer, 
                                   StackType_t **ppxIdleTaskStackBuffer, 
                                   uint32_t *pulIdleTaskStackSize);

static StaticTask_t xIdleTaskTCBBuffer;
static StackType_t xIdleStack[configMINIMAL_STACK_SIZE];

void vApplicationGetIdleTaskMemory(StaticTask_t **ppxIdleTaskTCBBuffer, 
                                   StackType_t **ppxIdleTaskStackBuffer, 
                                   uint32_t *pulIdleTaskStackSize) {
    *ppxIdleTaskTCBBuffer = &xIdleTaskTCBBuffer;
    *ppxIdleTaskStackBuffer = &xIdleStack[0];
    *pulIdleTaskStackSize = configMINIMAL_STACK_SIZE;
}
\end{lstlisting}

%%%%%%%%%%%%%%%%%%%%%%%%%%%%%%%%%%%%%%%%%%%%%%%%%%%%%%%%%%%%%%%%%%%%%%%%%%%%%%%
\section{Podsumowanie}
%%%%%%%%%%%%%%%%%%%%%%%%%%%%%%%%%%%%%%%%%%%%%%%%%%%%%%%%%%%%%%%%%%%%%%%%%%%%%%%

Projekt spełnia wszystkie wymagania funkcjonalne i dodatkowe:

\begin{enumerate}
    \item \textbf{Pomiar ze stałym okresem} -- \texttt{osDelay(PID\_DT\_MS)} zapewnia 30 ms okres próbkowania
    \item \textbf{Bezpieczny zakres sterowania} -- limity serwa 60--140 stopni
    \item \textbf{Uchyb ustalony} -- rolling average z 35 próbek, uchyb ustalony na poziomie <1\%
    \item \textbf{Zadawanie wartości referencyjnej} -- UART (komenda S:) i potencjometr (ADC PA0)
    \item \textbf{Podgląd sygnałów} -- ramki UART z danymi D/Z/A/F/E/V/S + CRC-8
    \item \textbf{Modularność i Doxygen} -- 7 modułów C, pełna dokumentacja API
    \item \textbf{Kontrola wersji} -- repozytorium Git
    \item \textbf{Aplikacja desktopowa} -- PySide6 (Qt) z wykresami PyQtGraph
    \item \textbf{Logowanie sygnałów} -- eksport do CSV z timestampami
    \item \textbf{Urządzenie wyjścia} -- 5 diod LED (PE2--PE6)
    \item \textbf{Urządzenie wejścia} -- potencjometr na ADC1\_CH0
    \item \textbf{Suma kontrolna CRC-8} -- wielomian 0x07, zgodna implementacja STM32/Python
    \item \textbf{FreeRTOS} -- 2 taski (ControlTask, DefaultTask)
\end{enumerate}

\end{document}

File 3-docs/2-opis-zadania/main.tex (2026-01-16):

\documentclass[12pt, a4paper]{article}

% Pakiety kodowania i językowe
\usepackage[utf8]{inputenc}
\usepackage[T1]{fontenc}
\usepackage[polish]{babel}

% Pakiety do geometrii i 
\usepackage{geometry}
\usepackage{graphicx}
\usepackage{float}
\usepackage{hyperref}
\usepackage{listings}
\usepackage{xcolor}

% Konfiguracja geometrii strony
\geometry{
    a4paper,
    left=25mm,
    top=25mm,
    bottom=25mm,
    right=25mm
}

% Konfiguracja linków
\hypersetup{
    colorlinks=true,
    linkcolor=black,
    filecolor=magenta,      
    urlcolor=blue,
}

% Konfiguracja wyświetlania kodu
\lstset{
    basicstyle=\ttfamily\footnotesize,
    breaklines=true,
    captionpos=b,
    frame=single,
    numbers=left,
    numberstyle=\tiny,
    keywordstyle=\color{blue},
    commentstyle=\color{green!60!black},
    stringstyle=\color{purple}
}

% Dane dokumentu
\title{Układ sterowania położeniem piłki pingpongowej na belce}
\author{Piotr Bednarek \\ Jan Andrzejewski \\ Mateusz Banaszak}
\date{\today}

\begin{document}

\maketitle

\section{Wstęp}
Przedmiotem projektu jest układ automatycznej regulacji pozycji piłki pingpongowej na
pochylonej belce. System wykorzystuje serwo TowerPro MG946R do sterowania kątem nachylenia belki
oraz laserowy czujnik odległości Time-of-Flight VL53L0X do pomiaru aktualnego położenia
piłki. Mikrokontroler STM32F767ZI analizuje dane z czujnika i w czasie rzeczywistym
koryguje nachylenie belki, aby utrzymać piłkę w zadanej pozycji lub śledzić określoną
trajektorię. Układ stanowi klasyczny przykład zastosowania regulacji PID w systemie
niestabilnym, gdzie niewielkie zakłócenia mogą prowadzić do utraty kontroli nad obiektem.

\section{Opis sprzętu}
Opis wykorzystanego mikrokontrolera (STM32) oraz peryferiów (czujniki, moduły).

\begin{itemize}
    \item STM Nucleo F767ZI
    \item Servo TowerPro MG946R
    \item Grove - VL53LOX Timeof Flight I2C
\end{itemize}

\begin{figure}[H]
    \centering
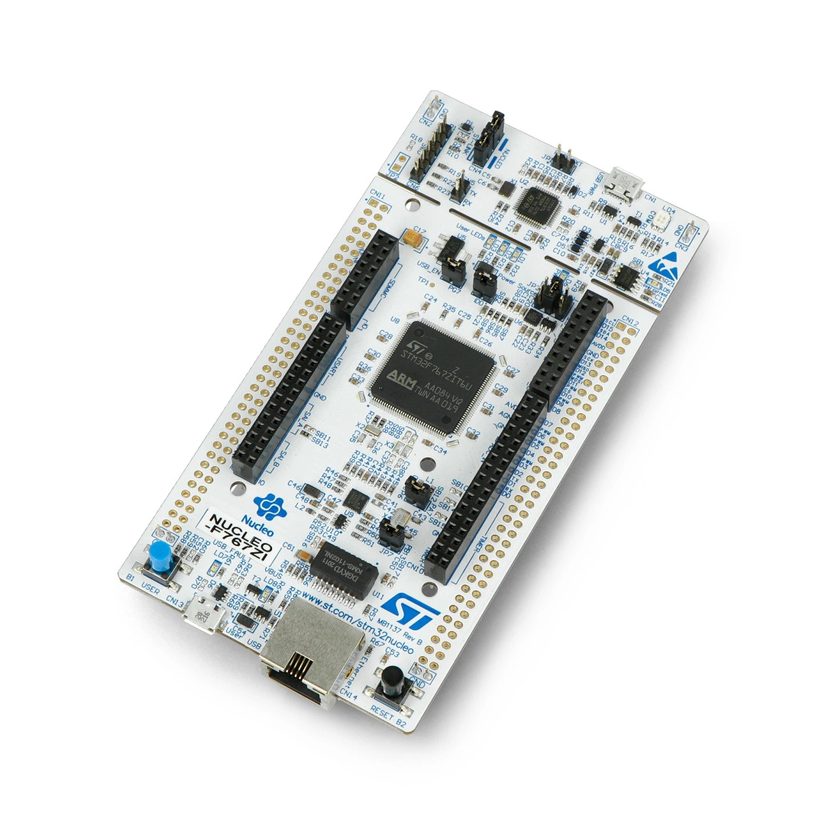
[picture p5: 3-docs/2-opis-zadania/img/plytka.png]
    
\end{figure}

\begin{figure}[H]
    \centering
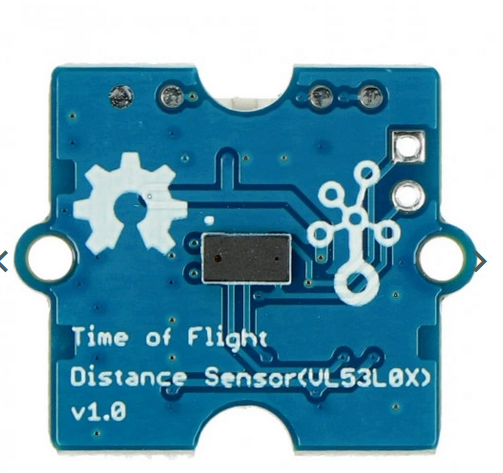
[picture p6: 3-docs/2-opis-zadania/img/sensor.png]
    
\end{figure}

\begin{figure}[H]
    \centering
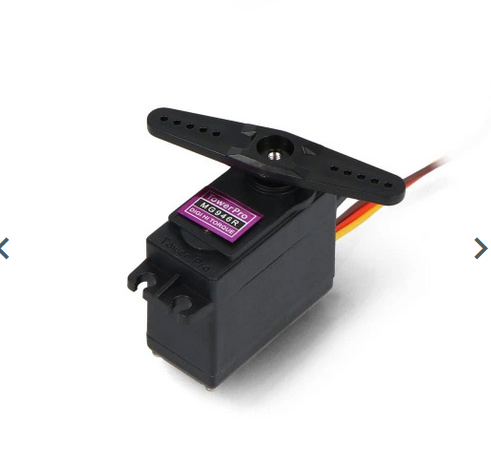
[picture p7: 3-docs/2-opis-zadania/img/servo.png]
    
\end{figure}

\section{Wymagania dodatkowe}
\begin{enumerate}
    \item Podział kodu źródłowego na moduły i dokumentacja kodu zgodna ze standardem dokumentacji.
    \item Wykorzystanie systemu kontroli wersji (Git) z publicznym repozytorium (GitHub).
    \item Dedykowana aplikacja desktopowa jako graficzny interfejs użytkownika
          zaprogramowana w Pythonie za pomocą nowoczesnych bibliotek.
          % \item Zapewnienie uchybu ustalonego na poziomie 1\% zakresu regulacji w stanie ustalonym za pomocą
          %   odpowiednio dostrojonego regulatora PID.
    \item Implementacja śledzenia sygnałów sterujących i pomiarowych za pomocą wykresów w aplikacji desktopowej (UI).
    \item Dodatkowe urządzenie wyjścia użytkownika za pomocą rzędu diod LED RGB do
          wizualizacji uchybu układu.
    \item Dodatkowe przyciski do manualnej zmiany kątu nachylenia belki lub wentylator wprowadzający
          zakłócenia do układu.
    \item Zapewnienie logow z procesu stabilizacji do odtworzenia przebiegow uchyby i wyjscia po przeprowadzeniu eksperymentu (CSV/TXT)
    \item Dodatkowe urządzenie wejścia użytkownika w postaci potencjometru do zmiany zadanej pozycji piłki na belce.
    \item Wykorzystanie sumy kontrolnej do wykrywania błędów transmisji w komunikacji szeregowej.
    \item Wykorzystanie systemu czasu rzeczywistego FreeRTOS.
\end{enumerate}

\section{Model/druk 3D}

\begin{figure}[H]
    \centering
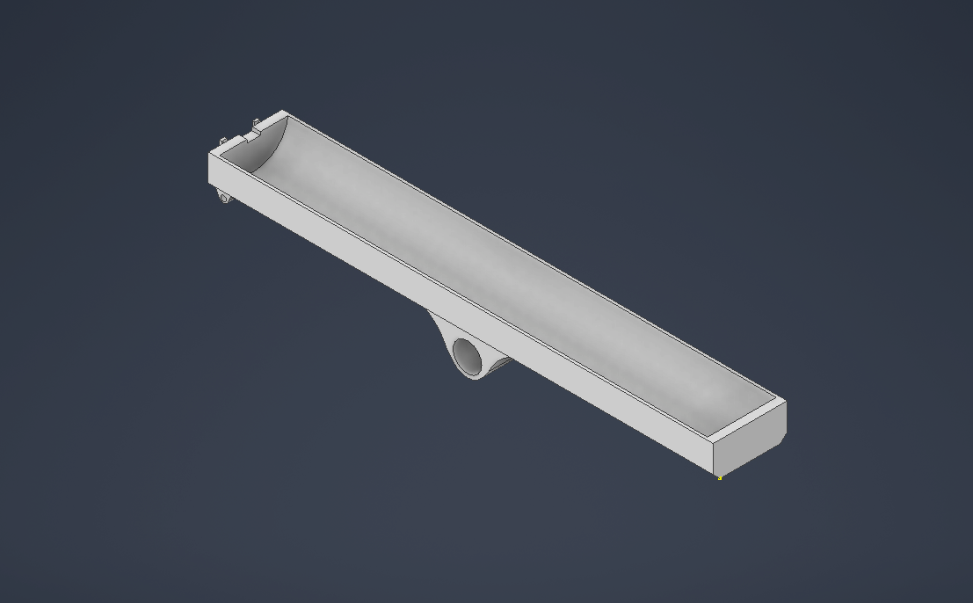
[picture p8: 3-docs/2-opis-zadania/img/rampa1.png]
    
\end{figure}

\begin{figure}[H]
    \centering
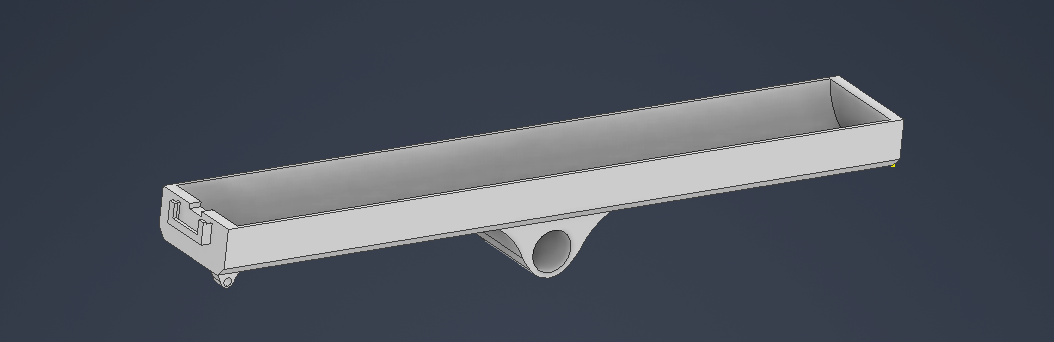
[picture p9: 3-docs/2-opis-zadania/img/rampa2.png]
    
\end{figure}

\end{document}

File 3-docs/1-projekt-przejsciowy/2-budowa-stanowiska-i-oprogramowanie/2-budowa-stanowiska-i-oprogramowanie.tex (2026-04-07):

% ROZDZIAŁ 2: Budowa stanowiska i oprogramowanie

\chapter{Budowa stanowiska i oprogramowanie}
\label{ch:budowa}

Niniejszy rozdział opisuje fizyczną budowę stanowiska laboratoryjnego, zastosowane
komponenty elektroniczne, środowisko programistyczne oraz architekturę oprogramowania
sterującego — firmware mikrokontrolera i~aplikację nadzorczą.

% -----------------------------------------------------------------------
\section{Opis stanowiska laboratoryjnego}
% -----------------------------------------------------------------------

Stanowisko składa się z~wydrukowanej w~technologii 3D pochyłej belki, po której
swobodnie toczy się metalowy walec (kulka).
Kąt nachylenia belki kontrolowany jest przez serwomechanek połączony z~belką
za pomocą dźwigni.
Pozycja kulki mierzona jest bezdotykowo za pomocą czujnika odległości ToF
zamontowanego na końcu belki.
Mikrokontroler STM32 odczytuje pomiar z~czujnika, oblicza sygnał sterujący
i~generuje odpowiedni sygnał PWM dla serwa.

\begin{figure}[H]
  \centering
  
  \caption{Stanowisko laboratoryjne układu kulka na belce}
  \label{fig:stanowisko}
\end{figure}

\subsection{Wykaz komponentów}

\begin{table}[H]
  \centering
  \caption{Komponenty sprzętowe stanowiska}
  \label{tab:komponenty}
  \begin{tabular}{lll}
    \toprule
    \textbf{Element} & \textbf{Model / opis} & \textbf{Interfejs} \\
    \midrule
    Mikrokontroler & STM32 Nucleo F767ZI & --- \\
    Serwomechanek  & TowerPro MG946R      & PWM 50\,Hz \\
    Czujnik odległości & Grove VL53L0X ToF & I\textsuperscript{2}C \\
    Potencjometr   & liniowy & ADC (PA0) \\
    Zasilacz       & 5\,V DC & --- \\
    \bottomrule
  \end{tabular}
\end{table}

% -----------------------------------------------------------------------
\section{Mikrokontroler STM32 i peryferia}
% -----------------------------------------------------------------------

\subsection{Mikrokontroler STM32F767ZI}

Głównym procesorem stanowiska jest mikrokontroler STM32F767ZI~\cite{stm32f767zi}
zamontowany na płytce ewaluacyjnej Nucleo-F767ZI.
Układ oparty jest na rdzeniu ARM Cortex-M7 taktowanym z~częstotliwością 216\,MHz
i~wyposażony jest w~bogatą gamę peryferiów: kilka interfejsów I\textsuperscript{2}C
i UART, timery sprzętowe, przetwornik ADC oraz obsługę sygnałów PWM.

\begin{figure}[H]
  \centering
  
  \caption{Płytka ewaluacyjna STM32 Nucleo-F767ZI}
\end{figure}

\subsection{Serwomechanek MG946R}

Do sterowania kątem belki zastosowano serwomechanek TowerPro MG946R.
Serwo przyjmuje sygnał PWM o~częstotliwości 50\,Hz i~czasie wypełnienia
od 1\,ms (pełne wychylenie w~jedną stronę) do 2\,ms (pełne wychylenie
w~drugą stronę).
Zakres roboczy ograniczony jest w~oprogramowaniu do 60--140° w~celu
zabezpieczenia mechaniki.

\begin{figure}[H]
  \centering
  
  \caption{Serwomechanek TowerPro MG946R}
\end{figure}

\subsection{Czujnik odległości VL53L0X}

Pozycja kulki mierzona jest czujnikiem VL53L0X~\cite{vl53l0x} firmy
STMicroelectronics, pracującym w~technologii Time-of-Flight (ToF).
Czujnik emituje krótkie impulsy laserowe podczerwieni i~mierzy czas
powrotu odbitego sygnału, co pozwala wyznaczyć odległość z~rozdzielczością
1\,mm w~zakresie do 2\,m.
Komunikacja z~mikrokontrolerem odbywa się przez magistralę I\textsuperscript{2}C.

\begin{figure}[H]
  \centering
  
  \caption{Czujnik odległości Grove VL53L0X Time-of-Flight}
\end{figure}

\subsection{Potencjometr}

Potencjometr liniowy podłączony do wejścia analogowego PA0 (ADC1\_CH0)
umożliwia ręczne zadawanie wartości referencyjnej pozycji kulki
w~trybie analogowym.
Przetwornik ADC skonfigurowany jest z~rozdzielczością 12-bitową
($0$--$4095$), co odpowiada zakresowi pozycji $0$--$250\,\mathrm{mm}$.

% -----------------------------------------------------------------------
\section{Środowisko programistyczne}
% -----------------------------------------------------------------------

\subsection{Firmware STM32}

Oprogramowanie mikrokontrolera zostało opracowane w~środowisku
STM32CubeIDE (Eclipse CDT ze zintegrowanym kompilatorem ARM GCC).
Konfigurację peryferiów (timery, I\textsuperscript{2}C, UART, ADC, PWM)
wygenerowano za pomocą narzędzia STM32CubeMX.
Kod źródłowy podzielono na osobne moduły~C zgodnie ze standardem Doxygen:

\begin{table}[H]
  \centering
  \caption{Moduły firmware}
  \label{tab:moduly}
  \begin{tabular}{ll}
    \toprule
    \textbf{Moduł} & \textbf{Opis} \\
    \midrule
    \texttt{main.c/h}       & Główna aplikacja, konfiguracja peryferiów \\
    \texttt{servo\_pid.c/h} & Regulator PID z~anti-windup \\
    \texttt{lqr.c/h}        & Regulator LQR (przestrzeń stanów) \\
    \texttt{filters.c/h}    & Filtry cyfrowe (EMA, mediana, 1-Euro) \\
    \texttt{crc8.c/h}       & Suma kontrolna CRC-8 \\
    \texttt{calibration.c/h}& Kalibracja czujnika VL53L0X \\
    \texttt{vl53l0x.c/h}    & Sterownik czujnika (I\textsuperscript{2}C) \\
    \bottomrule
  \end{tabular}
\end{table}

System operacyjny czasu rzeczywistego FreeRTOS zarządza wykonaniem dwóch
wątków (tasków):
\begin{itemize}
  \item \texttt{ControlTask} (priorytet wysoki) — pętla sterowania;
  \item \texttt{DefaultTask} (priorytet normalny) — obsługa komend UART.
\end{itemize}

\subsection{Aplikacja desktopowa}

Aplikacja nadzorcza napisana jest w~języku Python~3 z~wykorzystaniem
frameworka PySide6 (Qt~6).
Zapewnia ona:
\begin{itemize}
  \item połączenie z~mikrokontrolerem przez port szeregowy (pyserial),
  \item wizualizację sygnałów w~czasie rzeczywistym (pyqtgraph),
  \item zadawanie wartości referencyjnej i~nastaw regulatorów,
  \item nagrywanie danych i~eksport do pliku CSV,
  \item podgląd kamery z~detekcją pozycji kulki (OpenCV).
\end{itemize}

\begin{figure}[H]
  \centering
  
  \caption{Okno aplikacji desktopowej (PySide6)}
  \label{fig:desktop}
\end{figure}

% -----------------------------------------------------------------------
\section{Implementacja algorytmu sterowania}
% -----------------------------------------------------------------------

\subsection{Pętla sterowania i okres próbkowania}

Algorytm sterowania realizowany jest przez \texttt{ControlTask} z~ustalonym
okresem próbkowania 30\,ms wymuszonym przez funkcję \texttt{osDelay()}:

\begin{lstlisting}[style=cstyle, caption={Stały okres próbkowania w pętli sterowania (main.c)}]
#define PID_DT_MS 30

for (;;) {
    distance = readRangeContinuousMillimeters(&distanceStr);

    // obliczenia regulatora ...

    SetServoAngle(pid_output);
    osDelay(PID_DT_MS); // staly okres 30 ms
}
\end{lstlisting}

\subsection{Ograniczenie zakresu serwa}

Wyjście regulatora jest nasycane do bezpiecznego zakresu kąta serwa:

\begin{lstlisting}[style=cstyle, caption={Saturacja wyjścia i ograniczenia serwa (main.c)}]
#define SERVO_MIN_LIMIT  60.0f
#define SERVO_MAX_LIMIT 140.0f

if (pid_angle < SERVO_MIN_LIMIT)  pid_angle = SERVO_MIN_LIMIT;
if (pid_angle > SERVO_MAX_LIMIT)  pid_angle = SERVO_MAX_LIMIT;
SetServoAngle(pid_angle);
\end{lstlisting}

\subsection{Protokół telemetrii UART z sumą kontrolną CRC-8}

Dane pomiarowe przesyłane są przez UART~3 (115200\,baud) w~formacie
tekstowym z~sumą kontrolną CRC-8 (wielomian 0x07).
Format ramki:
\[
\texttt{D:\%d;Z:\%d;A:\%d;F:\%d;E:\%d;V:\%d;S:\%d;C:\%02X\textbackslash r\textbackslash n}
\]
gdzie kolejne pola oznaczają: surowy dystans, setpoint, kąt serwa,
dystans filtrowany, uchyb, średni uchyb, status czujnika i~CRC.

\begin{lstlisting}[style=cstyle, caption={Implementacja CRC-8 (crc8.c)}]
uint8_t CalculateCRC8(const char *data, int len) {
    uint8_t crc = 0x00;
    for (int i = 0; i < len; i++) {
        crc ^= data[i];
        for (uint8_t j = 0; j < 8; j++) {
            if (crc & 0x80)
                crc = (crc << 1) ^ 0x07;
            else
                crc <<= 1;
        }
    }
    return crc;
}
\end{lstlisting}

\subsection{Zadania FreeRTOS}

System operacyjny czasu rzeczywistego tworzy dwa wątki:

\begin{lstlisting}[style=cstyle, caption={Tworzenie zadań FreeRTOS (main.c)}]
osThreadDef(defaultTask, StartDefaultTask,
            osPriorityNormal, 0, 256);
defaultTaskHandle = osThreadCreate(osThread(defaultTask), NULL);

osThreadDef(ControlTask, StartControlTask,
            osPriorityHigh, 0, 1024);
ControlTaskHandle = osThreadCreate(osThread(ControlTask), NULL);

osKernelStart();
\end{lstlisting}

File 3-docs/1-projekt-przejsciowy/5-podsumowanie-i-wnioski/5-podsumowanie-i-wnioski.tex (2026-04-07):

% ROZDZIAŁ 5: Podsumowanie i wnioski

\chapter{Podsumowanie i wnioski}
\label{ch:wnioski}

% -----------------------------------------------------------------------
\section{Podsumowanie}
% -----------------------------------------------------------------------

W~ramach niniejszej pracy zaprojektowano i~zbudowano autonomiczne stanowisko
do sterowania pozycją kulki na belce oparte na mikrokontrolerze STM32F767ZI.
Zrealizowano pełny łańcuch: od identyfikacji modelu matematycznego obiektu,
przez projekt regulatorów PID i~LQR, po implementację firmware w~środowisku
FreeRTOS i~opracowanie aplikacji nadzorczej w~języku Python.

Stanowisko realizuje następujące funkcje:
\begin{itemize}
  \item pomiar pozycji kulki ze stałym okresem próbkowania 30\,ms (czujnik VL53L0X, FreeRTOS),
  \item sterowanie kątem belki w~bezpiecznym zakresie (60--140°) z~zabezpieczeniem
        przed nasyceniem wyjścia regulatora,
  \item zadawanie wartości referencyjnej przez UART lub potencjometr (ADC),
  \item telemetria przez UART z~sumą kontrolną CRC-8,
  \item nagrywanie sygnałów do pliku CSV i~wizualizacja w~czasie rzeczywistym
        w~aplikacji desktopowej PySide6.
\end{itemize}

% -----------------------------------------------------------------------
\section{Wnioski}
% -----------------------------------------------------------------------

Na podstawie przeprowadzonych prac sformułowano następujące wnioski:

\begin{enumerate}
  \item \textbf{Regulator PID} okazał się wystarczający do stabilizacji kulki
        w~zadanej pozycji przy typowych warunkach pracy stanowiska.
        Uchyb ustalony osiągał poziom poniżej~1\% zakresu regulacji (2{,}5\,mm
        przy zakresie 250\,mm) po prawidłowym dostrojeniu nastaw.

  \item \textbf{Dynamika serwa} i~\textbf{przekładnia mechaniczna} stanowią
        dominujące parametry wpływające na czas regulacji.
        Stała czasowa serwa $T_{\mathrm{serwo}} = 0{,}095\,\mathrm{s}$
        oraz przekładnia $k_{\mathrm{mech}} = 0{,}2$ wyznaczają
        pasmo przenoszenia układu w~zamkniętej pętli regulacji.

  \item \textbf{Protokół CRC-8} okazał się niezawodny w~komunikacji
        UART pomiędzy mikrokontrolerem a~aplikacją desktopową.

  \item \textbf{Architektura FreeRTOS} z~podziałem na \texttt{ControlTask}
        i~\texttt{DefaultTask} zapewniła deterministyczny czas wykonania
        pętli sterowania niezależnie od aktywności pozostałych zadań.

  \item \textbf{Czujnik VL53L0X} sprawdził się jako precyzyjne źródło
        pomiaru pozycji kulki; zakres pomiarowy 250\,mm pokrywał pełną
        długość roboczą belki.
\end{enumerate}

% -----------------------------------------------------------------------
\section{Kierunki dalszych badań}
% -----------------------------------------------------------------------

Na podstawie doświadczeń zebranych podczas realizacji projektu wskazano
następujące kierunki możliwego rozwoju stanowiska:

\begin{itemize}
  \item \textbf{Finalizacja regulatora LQR} — zaimplementowany moduł
        \texttt{lqr.c} wymaga dalszego strojenia macierzy $Q$ i~$R$;
        oczekuje się krótszego czasu regulacji i~mniejszego przeregulowania
        w~stosunku do PID.

  \item \textbf{Estymacja stanu (obserwator Luenbergera / filtr Kalmana)} —
        prędkość kulki $\dot{x}$ jest aktualnie obliczana przez różniczkowanie
        numeryczne, co jest wrażliwe na szum pomiarowy.
        Implementacja obserwatora stanu pozwoliłaby uzyskać bardziej
        gładkie estymaty prędkości.

  \item \textbf{Wizualna detekcja pozycji kulki} — kamera podłączona do
        komputera nadzorczego i~algorytm detekcji okręgów (przestrzeń barw
        HSV + transformata Hougha) mogą służyć jako niezależna metoda
        weryfikacji pomiaru ToF.

  \item \textbf{Poprawiona identyfikacja modelu} — zastosowanie APRBS
        z~właściwie dobranymi parametrami (długość sekwencji, amplituda)
        umożliwiłoby pełniejszą identyfikację funkcji przejścia, w~szczególności
        dynamiki nieliniowej przy dużych kątach.

  \item \textbf{Śledzenie trajektorii} — rozszerzenie aplikacji desktopowej
        o~generowanie predefiniowanych trajektorii referencyjnych
        (sinusoidalnych, trapezoidalnych) i~ocenę błędu śledzenia.
\end{itemize}

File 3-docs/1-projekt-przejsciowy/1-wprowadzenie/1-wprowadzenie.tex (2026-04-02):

% ROZDZIAŁ 1: Wprowadzenie

\chapter{Wprowadzenie}

Układ kulka na belce (\textit{ball and beam}) jest klasycznym laboratoryjnym obiektem sterowania,
powszechnie stosowanym w dydaktyce automatyki ze względu na prostą budowę mechaniczną
i zarazem nieliniową, niestabilną dynamikę \cite{bolivar2014modelling}.
Zadanie sterowania polega na utrzymaniu toczącego się swobodnie po belce metalowego walca
w~zadanej pozycji poprzez regulację kąta wychylenia belki napędzanej serwomechanizmem.
Pomimo pozornej prostoty obiekt ten wymaga zastosowania metod nowoczesnej teorii sterowania,
co czyni go idealną platformą do weryfikacji algorytmów regulacji zarówno klasycznych, jak i optymalnych.

\section{Cel i zakres pracy}

Celem niniejszej pracy jest zaprojektowanie i zbudowanie autonomicznego stanowiska
sterowania kulką na belce opartego na mikrokontrolerze STM32F767ZI \cite{stm32f767zi}
oraz zaimplementowanie i porównanie dwóch algorytmów regulacji:
\begin{itemize}
  \item regulatora \textbf{PID} z filtrem pochodnej, członem anti-windup i strojeniem
        w~oparciu o odpowiedź skokową i sygnał APRBS,
  \item regulatora \textbf{LQR} (\textit{Linear Quadratic Regulator}) w~przestrzeni stanów
        z~wektorem stanu obejmującym pozycję kulki, jej prędkość oraz kąt belki.
\end{itemize}

Zakres pracy obejmuje:
\begin{enumerate}[(i)]
  \item identyfikację modelu matematycznego obiektu metodami doświadczalnymi,
  \item projektowanie i dobór nastaw regulatorów PID oraz LQR,
  \item budowę stanowiska laboratoryjnego z czujnikiem ToF VL53L0X \cite{vl53l0x}
        i serwomechanizmem MG90S,
  \item implementację algorytmów w środowisku FreeRTOS na platformie STM32,
  \item opracowanie aplikacji nadzorczej w języku Python~(PySide6) z podglądem
        kamery i detekcją pozycji kulki metodami wizji komputerowej \cite{kadam2024object},
  \item eksperymentalną weryfikację i porównanie obu strategii sterowania.
\end{enumerate}

\section{Przegląd literatury}

Układ kulka na belce jest od dziesięcioleci obiektem intensywnych badań w dziedzinie
automatyki i robotyki.
Pierwszym krokiem projektowania regulatora jest zawsze wyprowadzenie modelu matematycznego.
Bolívar-Vincenty i Beauchamp-Báez \cite{bolivar2014modelling} wykazali, że równania ruchu
otrzymane metodą Newtona i metodą Lagrange'a są tożsame, o ile poprawnie uwzględni się
człony wynikające z obrotu układu odniesienia — błąd często popełniany w literaturze.
Autorzy wyprowadzają nieliniowe równania stanu, a następnie linearyzują je w otoczeniu
punktu równowagi, uzyskując transmitancję i liniowy model przestrzeni stanów, stanowiący
punkt wyjścia do syntezy regulatora.

Wśród klasycznych podejść do sterowania układem dominuje regulator PID.
Taifour Ali i~in. \cite{taifour2017design} przedstawili implementację dwupętlowego
regulatora PID na mikrokontrolerze Arduino z ultradźwiękowym czujnikiem odległości
i serwomechanizmem DC.
Autorzy potwierdzili skuteczność ręcznego doboru nastaw metodą prób i błędów,
uzyskując stabilizację z minimalnymi oscylacjami przy $K_p{=}4$, $K_i{=}1$, $K_d{=}2$.
W pracy wykazano, że dołączenie członu całkującego istotnie redukuje uchyb ustalony,
a pochodna skraca czas regulacji i tłumi przeregulowania.

Projektowanie optymalnych regulatorów stanu wymaga solidnych podstaw teoretycznych.
Ogata \cite{ogata2010modern} oraz Franklin i~in. \cite{franklin2014feedback} dostarczają
kompletnego opisu teorii przestrzeni stanów, analizy sterowalności i obserwowalności
oraz syntezy LQR minimalizującego wskaźnik jakości kwadratowej.
W niniejszej pracy macierze wag $\mathbf{Q}$ i $R$ dobrano metodą iteracyjną
z pomocą środowiska MATLAB/Simulink, a uzyskane wzmocnienia $\mathbf{K}$ przeniesiono
bezpośrednio do firmware'u mikrokontrolera.

Dodatkową funkcją stanowiska jest wizualna weryfikacja pozycji kulki za pomocą kamery.
Przegląd metod śledzenia obiektów w wizji komputerowej przeprowadzony przez
Kadama i~in. \cite{kadam2024object} wskazuje, że klasyczne podejście oparte na transformacji
przestrzeni barw HSV i detekcji okręgów metodą Hougha pozostaje skuteczne dla
obiektów o~regularnym kształcie i~kontrolowanym oświetleniu — warunki spełnione
na stanowisku laboratoryjnym.
Głębsze metody uczenia maszynowego byłyby uzasadnione w środowiskach o zmiennym tle
lub przy wielu obiektach; dla niniejszego zastosowania przyjęto rozwiązanie klasyczne.

\section{Struktura pracy}

Praca podzielona jest na pięć rozdziałów.
Rozdział~\ref{ch:budowa} opisuje budowę mechaniczną i elektryczną stanowiska
oraz architekturę oprogramowania — firmware FreeRTOS i aplikację nadzorczą Python.
Rozdział~\ref{ch:model} zawiera wyprowadzenie modelu matematycznego obiektu
metodą Lagrange'a, linearyzację w punkcie pracy oraz projekt regulatorów PID i~LQR.
Rozdział~\ref{ch:wyniki} prezentuje wyniki eksperymentów identyfikacyjnych i regulacyjnych,
w tym porównanie charakterystyk skokowych obu strategii sterowania.
Rozdział~\ref{ch:wnioski} podsumowuje pracę i wskazuje kierunki dalszych badań.

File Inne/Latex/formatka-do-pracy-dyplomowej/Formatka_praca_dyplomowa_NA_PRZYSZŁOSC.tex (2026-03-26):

% Preambuła: definicja klasy dokumentu i lista potrzebnych pakietów ///////////////////////////////////////////////////////////////////////////////////////////////////////

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

% Konfiguracja nagłówka, stopki (w tym wyglądu i sposobu numeracji stron) i wyglądu tytułów głównych rozdziałów ///////////////////////////////////////////////

\pagestyle{fancy}
\cfoot{\thepage}
\fancyhead{} % czyści wszystkie pola w nagłówku
\fancyhead[RO,LE]{\textit {\textsl{Tytuł pracy} \ldots}} % tekst w nagłówku
\fancyfoot{} % czyści wszystkie pola w stopce
\fancyfoot[C]{\thepage} % numery stron w stopce; wycentrowane

\titleformat{\chapter}[display]
  {\normalfont\Large\raggedleft}
  {\MakeUppercase{\chaptertitlename}
    \rlap{ \resizebox{!}{1.5cm}{\thechapter} \rule{5cm}{1.5cm}}}
  {10pt}{\Huge}
\titlespacing*{\chapter}{0pt}{30pt}{50pt} % odstępy w tytule głównym

% Początek dokumenty ///////////////////////////////////////////////////////////////////////////////////////////////////////////////////////////////////////////////////////////////
\begin{document}

  % Strona tytułowa
\begin{titlepage}

\vspace*{-2cm} % odstęp pionowy

\begin{center} % wypośrodkuj
\Large \textbf{POLITECHNIKA POZNAŃSKA}\\[1mm]
\Large {WYDZIAŁ ELEKTRYCZNY}\\[1mm]
\begin{large}
Instytut Elektroenergetyki\\[1mm]
Zakład Wysokich Napięć i Materiałów Elektrotechnicznych\\[1cm]
\end{large}
\end{center}

\begin{center}

\end{center}

\vspace{1cm}

\begin{center}
\Large \textbf {Imię Nazwisko}
\end{center}

\vspace{1cm}

\begin{center}
\Large \textbf{\textit{TYTUŁ PRACY DYPLOMOWEJ}}
\end{center}

\vspace{3cm}
\hfill
\textbf {Promotor}: dr inż. Imię Nazwisko

\vspace{2cm}

 \hspace*{-1cm}
\begin{minipage}{7cm}
\centering
Pracę przyjmuję i akceptuję\\

\vspace{0.5cm}

................................................\\

\textit{\footnotesize data i podpis opiekuna pracy}
\end{minipage}

\vspace{2.5cm}

\begin{center}
Poznań, \the\year
\end{center}

  % Pusta strona  (w tym miejscu karta tematu z Dziekanatu) \\\\\\\\\\\\\\\\\\\\\\\\\\\\\\\\\\\\\\\\\\\\\\\\\\\\\\\\\\\\\\\\\\\\\\\\\\\\\\\\\\\\\\\\\\\\\\\\\\\\\\\\\\\\\\\\\\
\newpage\null\thispagestyle{empty}\newpage

 % Streszczenie \\\\\\\\\\\\\\\\\\\\\\\\\\\\\\\\\\\\\\\\\\\\\\\\\\\\\\\\\\\\\\\\\\\\\\\\\\\\\\\\\\\\\\\\\\\\\\\\\\\\\\\\\\\\\\\\\\\\\\\\\\\\\\\\\\\\\\\\\\\\\\\\\\\\\\\\\\\\\\\\\\\\\\\
    \newpage\thispagestyle{empty}
    \vspace*{2\baselineskip}
    \begin{center}
	{\large\bfseries Streszczenie}\par\bigskip
    \end{center}

    {\itshape
    % Treść streszczenia
    }
    \vspace*{1\baselineskip}

    \noindent{\bf Słowa kluczowe}: {\itshape słowo1, słowo2.}
    \par
    \vspace{4\baselineskip}

  % Abstract \\\\\\\\\\\\\\\\\\\\\\\\\\\\\\\\\\\\\\\\\\\\\\\\\\\\\\\\\\\\\\\\\\\\\\\\\\\\\\\\\\\\\\\\\\\\\\\\\\\\\\\\\\\\\\\\\\\\\\\\\\\\\\\\\\\\\\\\\\\\\\\\\\\\\\\\\\\\\\\\\\\\\\\\\\\
    \begin{center}
	{\large\bfseries Abstract}\par\bigskip
    \end{center}
    \noindent{\bf Title}: {\itshape Title of the thesis.}\par
    \vspace*{1\baselineskip}
    {\itshape
    % Abstract content
    }
    \vspace*{1\baselineskip}

    \noindent{\bf Key words}: {\itshape keyword1, keyword2.}

\end{titlepage}

  % Spis treści ]\\\\\\\\\\\\\\\\\\\\\\\\\\\\\\\\\\\\\\\\\\\\\\\\\\\\\\\\\\\\\\\\\\\\\\\\\\\\\\\\\\\\\\\\\\\\\\\\\\\\\\\\\\\\\\\\\\\\\\\\\\\\\\\\\\\\\\\\\\\\\\\\\\\\\\\\\\\\\\\\\\\\\\\\\

\tableofcontents % wstawia spis treści

 % Główna część pracy \\\\\\\\\\\\\\\\\\\\\\\\\\\\\\\\\\\\\\\\\\\\\\\\\\\\\\\\\\\\\\\\\\\\\\\\\\\\\\\\\\\\\\\\\\\\\\\\\\\\\\\\\\\\\\\\\\\\\\\\\\\\\\\\\\\\\\\\\\\\\\\\\\\

% WSTĘP _____________________________________________________________________________________________________________________
\chapter*{Wstęp} % rozdział nienumerowany (dlatego *)
\addcontentsline{toc}{chapter}{Wstęp} % uwzględnia nienumerowany rozdział <Wstęp> w <Spisie treści>

% ROZDZIAŁ 1 _________________________________________________________________________________________________________________
\input{1-wprowadzenie/1-wprowadzenie}

% ROZDZIAŁ 2 _________________________________________________________________________________________________________________
\input{2-budowa-stanowiska-i-oprogramowanie/2-budowa-stanowiska-i-oprogramowanie}

% ROZDZIAŁ 3 _________________________________________________________________________________________________________________
\input{3-model-matematyczny-i-projekt-regulacji/3-model-matematyczny-i-projekt-regulacji}

% ROZDZIAŁ 4 _________________________________________________________________________________________________________________
\input{4-wyniki-eksperymentalne/4-wyniki-eksperymentalne}

% ROZDZIAŁ 5 _________________________________________________________________________________________________________________
\input{5-podsumowanie-i-wnioski/5-podsumowanie-i-wnioski}

% BIBLIOGRAFIA ___________________________________________________________________________________________________________
\bibliographystyle{unsrt} % kolejność cytowania w tekście
\bibliography{bibliografia}

\listoffigures
\appendix

\end{document}

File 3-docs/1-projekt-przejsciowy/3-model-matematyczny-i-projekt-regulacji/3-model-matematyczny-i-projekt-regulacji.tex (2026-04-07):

% ROZDZIAŁ 3: Model matematyczny i projekt regulacji

\chapter{Model matematyczny i projekt regulacji}
\label{ch:model}

Rozdział ten przedstawia wyprowadzenie modelu matematycznego układu kulka na belce,
metodę identyfikacji jego parametrów oraz projekt regulatorów PID i~LQR.

% -----------------------------------------------------------------------
\section{Model matematyczny obiektu regulacji}
% -----------------------------------------------------------------------

Układ składa się z~trzech elementów połączonych szeregowo: serwomechanizmu,
mechanicznego połączenia dźwigniowego oraz kulki toczącej się po belce.

\subsection{Dynamika serwomechanizmu}

Dynamikę serwomechanizmu w~pierwszym przybliżeniu opisuje człon inercyjny
pierwszego rzędu:
\begin{equation}
  G_{\mathrm{serwo}}(s) = \frac{\Theta_{\mathrm{serwo}}(s)}{\Theta_{\mathrm{ref}}(S)} = \frac{1}{T_{\mathrm{serwo}}\,s+1},
\end{equation}
gdzie $T_{\mathrm{serwo}}$ jest stałą czasową serwa.

Na podstawie danych katalogowych serwomechanizmu MG946R
(0{,}20\,s/60° przy 4{,}8\,V; 0{,}11\,s/60° przy 6\,V)
interpolując dla napięcia 5\,V:
\begin{equation}
  V_{5\mathrm{V}} \approx 0{,}20 - \frac{0{,}09}{1{,}2} \cdot 0{,}2 \approx 0{,}185\,\mathrm{s}/60^{\circ}.
\end{equation}
Przyjęto stałą czasową $T_{\mathrm{serwo}} = 0{,}095\,\mathrm{s}$.

\subsection{Dynamika kulki na belce}

\subsubsection{Równanie ruchu — II zasada dynamiki}

\begin{figure}[H]
  \centering
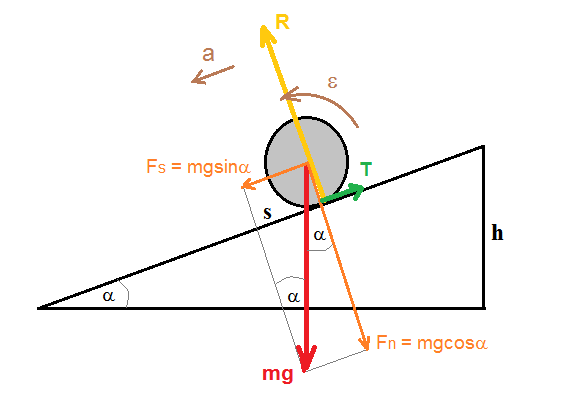
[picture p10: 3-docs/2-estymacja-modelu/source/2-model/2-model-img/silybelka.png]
  
  \caption{Rozkład sił działających na kulkę na równi pochyłej}
  \label{fig:silybelka}
\end{figure}

Dla kulki toczącej się bez poślizgu po belce pochylonej pod kątem $\theta$
równanie ruchu postępowego wynosi:
\begin{equation}
  m\ddot{x} = m\,g\sin\theta - T,
\end{equation}
a równanie momentu obrotowego wokół osi kulki:
\begin{equation}
  T \cdot R = J\,\ddot{\alpha},
\end{equation}
gdzie $T$ — siła tarcia statycznego, $R$ — promień kulki, $J$ — moment bezwładności,
$\ddot\alpha$ — przyspieszenie kątowe kulki.

\subsubsection{Warunek toczenia bez poślizgu}

Z~warunku $\ddot x = \ddot\alpha\cdot R$ eliminuje się siłę tarcia:
\begin{equation}
  m\ddot{x} + \frac{J}{R^2}\ddot{x} = m\,g\sin\theta
  \quad\Rightarrow\quad
  \ddot{x} = \frac{g\sin\theta}{1 + J/(mR^2)}.
\end{equation}

Dla małych kątów $\sin\theta\approx\theta$, a~dla walcowej kulki
$J = \tfrac{2}{3}mR^2$, stąd:
\begin{equation}
  \ddot{x} = \underbrace{\frac{g}{1 + 2/3}}_{c_{\mathrm{ball}}} \cdot\theta
  = 0{,}6\,g\cdot\theta.
\end{equation}

Stała dynamiki kulki wynosi:
\begin{equation}
  c_{\mathrm{ball}} = 0{,}6 \times 9{,}81 = 5{,}886\,\mathrm{m/s^2}.
\end{equation}

\subsubsection{Transmitancja kulki na belce}

Po zastosowaniu transformaty Laplace'a (zerowe warunki początkowe):
\begin{equation}
  G_{\mathrm{ball}}(s) = \frac{X(s)}{\Theta_{\mathrm{beam}}(s)} = \frac{c_{\mathrm{ball}}}{s^2}.
\end{equation}

\subsection{Połączenie mechaniczne i transmitancja całkowita}

\begin{figure}[H]
  \centering
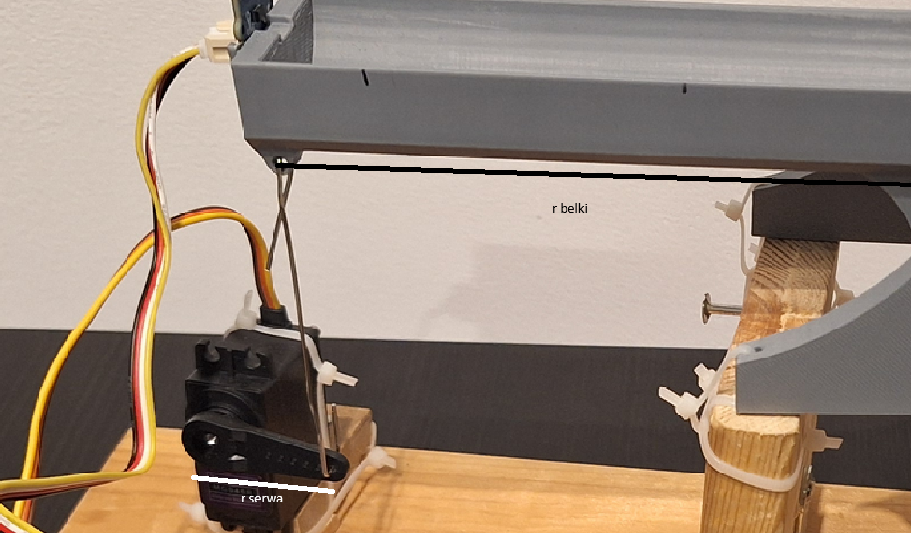
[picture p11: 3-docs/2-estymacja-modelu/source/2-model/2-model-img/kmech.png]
  
  \caption{Schemat mechanicznego połączenia serwa z~belką (dźwignia)}
  \label{fig:kmech}
\end{figure}

Kąty serwa i~belki powiązane są przez przekładnię mechaniczną:
\begin{equation}
  \theta_{\mathrm{beam}} = \frac{r_{\mathrm{serwo}}}{r_{\mathrm{belka}}} \cdot \theta_{\mathrm{serwo}}
  = k_{\mathrm{mech}} \cdot \theta_{\mathrm{serwo}},
\end{equation}
gdzie $r_{\mathrm{serwo}} = 3\,\mathrm{cm}$, $r_{\mathrm{belka}} = 15\,\mathrm{cm}$,
zatem $k_{\mathrm{mech}} = 0{,}2$.

Całkowita transmitancja układu (od sygnału sterującego $U(s)$ do pozycji kulki $X(s)$):
\begin{equation}
  G_{\mathrm{total}}(s) = k_{\mathrm{mech}} \cdot G_{\mathrm{serwo}}(s) \cdot G_{\mathrm{ball}}(s)
  = \frac{k_{\mathrm{mech}}\cdot c_{\mathrm{ball}}}{s^2(T_{\mathrm{serwo}}\,s+1)}.
  \label{eq:Gtotal}
\end{equation}

Podstawiając wartości liczbowe:
\begin{equation}
  G_{\mathrm{total}}(s) = \frac{0{,}2\times 5{,}886}{0{,}095\,s^3 + s^2}
  = \frac{1{,}177}{0{,}095\,s^3 + s^2}.
\end{equation}

% -----------------------------------------------------------------------
\section{Identyfikacja parametrów modelu}
% -----------------------------------------------------------------------

\subsection{Sygnał PRBS}

Do identyfikacji parametrów serwa zastosowano sygnał PRBS
(\textit{Pseudo Random Binary Sequence}) — deterministyczną sekwencję
dwustanową o~właściwościach szumopodobnych.
PRBS zapewnia szerokie widmo częstotliwościowe i~ograniczoną amplitudę,
co jest istotne ze względu na stabilność mechaniki stanowiska.

Ze względu na ograniczoną możliwość doboru parametrów PRBS
(długości sekwencji i~czasu trwania bitu) pokrywających pełną dynamikę
obiektu, wyniki identyfikacji oparto ostatecznie na odpowiedzi skokowej
i~danych katalogowych serwomechanizmu.

\subsection{Przyjęte parametry modelu}

\begin{table}[H]
  \centering
  \caption{Parametry numeryczne modelu}
  \label{tab:parametry}
  \begin{tabular}{lll}
    \toprule
    \textbf{Parametr} & \textbf{Wartość} & \textbf{Źródło} \\
    \midrule
    $T_{\mathrm{serwo}}$ & $0{,}095\,\mathrm{s}$ & karta katalogowa, interpolacja \\
    $c_{\mathrm{ball}}$  & $5{,}886\,\mathrm{m/s^2}$ & wyprowadzenie analityczne \\
    $k_{\mathrm{mech}}$  & $0{,}20$ & pomiar geometryczny ($3\,\mathrm{cm}/15\,\mathrm{cm}$) \\
    \bottomrule
  \end{tabular}
\end{table}

% -----------------------------------------------------------------------
\section{Projekt regulatora}
% -----------------------------------------------------------------------

\subsection{Opis przestrzeni stanów}

Jako wektor stanu przyjęto trzy fizycznie mierzalne wielkości:
\begin{equation}
  \mathbf{x} = \begin{bmatrix} x \\ \dot{x} \\ \theta \end{bmatrix},
\end{equation}
gdzie $x$ — pozycja kulki, $\dot{x}$ — prędkość kulki, $\theta$ — kąt serwa (belki).

Wyprowadzając równania różniczkowe z~bloków transmitancyjnych, otrzymuje się model
przestrzeni stanów w~postaci $\dot{\mathbf{x}} = A\mathbf{x} + Bu$, $y = C\mathbf{x}$:

\begin{equation}
  \begin{bmatrix} \dot{x}_1 \\ \dot{x}_2 \\ \dot{x}_3 \end{bmatrix}
  =
  \begin{bmatrix} 0 & 1 & 0 \\ 0 & 0 & c_{\mathrm{ball}} \\ 0 & 0 & -1/T_{\mathrm{serwo}} \end{bmatrix}
  \begin{bmatrix} x_1 \\ x_2 \\ x_3 \end{bmatrix}
  +
  \begin{bmatrix} 0 \\ 0 \\ 1/T_{\mathrm{serwo}} \end{bmatrix} u,
  \label{eq:statespace}
\end{equation}

\begin{equation}
  y = \begin{bmatrix} 1 & 0 & 0 \end{bmatrix} \mathbf{x}.
\end{equation}

Podstawiając wartości liczbowe ($c_{\mathrm{ball}} = 5{,}886$, $T_{\mathrm{serwo}} = 0{,}095$):

\begin{equation}
  A = \begin{bmatrix} 0 & 1 & 0 \\ 0 & 0 & 5{,}886 \\ 0 & 0 & -10{,}526 \end{bmatrix},
  \quad
  B = \begin{bmatrix} 0 \\ 0 \\ 10{,}526 \end{bmatrix},
  \quad
  C = \begin{bmatrix} 1 & 0 & 0 \end{bmatrix}.
\end{equation}

\subsection{Sterowalność}

Macierz sterowalności $\mathcal{C} = [B\;AB\;A^2B]$:

\begin{equation}
  \mathcal{C} = \begin{bmatrix}
    0       &  0       & 12{,}389 \\
    0       & 12{,}389 & -110{,}796 \\
    10{,}526 & -110{,}796 & 1{,}166\times10^3
  \end{bmatrix}.
\end{equation}

Wyznacznik:
\begin{equation}
  \det(\mathcal{C}) = 12{,}389 \times (-130{,}380) \approx -1614 \neq 0.
\end{equation}

Macierz ma pełny rząd~3, zatem układ jest \textbf{w~pełni sterowalny} —
możliwe jest zaprojektowanie efektywnego regulatora stanu (LQR).

\subsection{Obserwowalność}

Macierz obserwowalności $\mathcal{O} = [C;\;CA;\;CA^2]^T$:

\begin{equation}
  \mathcal{O} = \begin{bmatrix}
    1 & 0 & 0 \\
    0 & 1 & 0 \\
    0 & 0 & 1{,}177
  \end{bmatrix}, \quad
  \det(\mathcal{O}) = 1{,}177 \neq 0.
\end{equation}

Rząd wynosi~3, układ jest \textbf{w~pełni obserwowalny} — wszystkie stany
można zrekonstruować z~pomiaru pozycji kulki $x$.

\subsection{Regulator PID}

W~firmware mikrokontrolera zaimplementowano klasyczny regulator PID
z~następującymi modyfikacjami:
\begin{itemize}
  \item \textbf{pochodna na pomiarze} — różniczkowanie sygnału wyjścia
        (nie uchybu), co eliminuje skok pochodnej przy zmianie wartości zadanej;
  \item \textbf{anti-windup} (ograniczenie członu całkującego) — zapobiega
        nasyceniu członu~I przy wysyceniu wyjścia;
  \item \textbf{dyskretyzacja} — metoda prostokątów (Euler przód)
        z~krokiem $T_s = 30\,\mathrm{ms}$.
\end{itemize}

Nastawy regulatora PID ($K_p$, $K_i$, $K_d$) dobierane są iteracyjnie
i~przesyłane do mikrokontrolera w~czasie rzeczywistym przez aplikację
desktopową bez konieczności ponownego programowania układu.

\subsection{Regulator LQR}

Regulator LQR (\textit{Linear Quadratic Regulator}) minimalizuje wskaźnik
jakości kwadratowej:
\begin{equation}
  J = \int_0^\infty \left( \mathbf{x}^T Q\,\mathbf{x} + u^T R\,u \right) dt,
\end{equation}
gdzie macierze wag $Q$ (penalizacja stanów) i~$R$ (penalizacja wejścia)
dobrano metodą iteracyjną w~środowisku MATLAB/Simulink.
Uzyskany wektor wzmocnień $\mathbf{K}$ przeniesiono bezpośrednio do modułu
\texttt{lqr.c} firmware.
Sygnał sterujący wyznaczany jest jako:
\begin{equation}
  u = -\mathbf{K}\,\mathbf{x} = -[K_1\;K_2\;K_3]\begin{bmatrix} x \\ \dot{x} \\ \theta \end{bmatrix}.
\end{equation}

% -----------------------------------------------------------------------
\section{Symulacja układu regulacji}
% -----------------------------------------------------------------------

Model układu w~przestrzeni stanów~\eqref{eq:statespace} zaimplementowano
w~środowisku MATLAB/Simulink (plik \texttt{5-matlab/ballonbeam\_matlab1.slx}).
Model posłużył do wstępnego doboru nastaw regulatorów przed weryfikacją
eksperymentalną na rzeczywistym stanowisku.
Szczegółowe wyniki symulacji porównawczych (PID vs.\ LQR) stanowią
uzupełnienie niniejszej pracy.

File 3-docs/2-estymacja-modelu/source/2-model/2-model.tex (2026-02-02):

\section{Model}

\subsection{Dynamika serwa}

Dynamikę serwomechanizmu w pierwszym przybliżeniu opisuje się jako człon
inercyjny I rzędu:
\begin{equation}
  G_{\mathrm{serwo}}(s)=\frac{1}{Ts+1},
\end{equation}
gdzie $T$ jest stałą czasową (im mniejsza wartość $T$, tym szybsza odpowiedź na
skok sygnału sterującego).

Transmitancja serwa $G_{\mathrm{serwo}}(s)$ jest stosunkiem transformaty Laplace'a 
kąta serwa $\Theta_{\mathrm{serwo}}(s)$ do transformaty Laplace'a sygnału wejściowego 
(napięcia sterującego) $U(s)$ w dziedzinie Laplace'a:
\begin{equation}
  G_{\mathrm{serwo}}(s) = \frac{\Theta_{\mathrm{serwo}}(s)}{U(s)}
\end{equation}

W kartach katalogowych serwomechanizmów podawana jest zwykle prędkość typu
„$t\,\mathrm{s}/60^{\circ}$”, która opisuje maksymalną szybkość przestawiania
(\emph{slew rate}), a nie bezpośrednio stałą czasową $T$. W modelu uproszczonym
przyjmuje się jednak, że wraz ze wzrostem prędkości katalogowej maleje efektywna
stała czasowa.

W nocie katalogowe do serwa podano predkosci przy róznych napieciach zasilania:
\begin{itemize}
  \item $0{,}20\,\mathrm{s}/60^{\circ}$ przy $4{,}8\,\mathrm{V}$,
  \item $0{,}11\,\mathrm{s}/60^{\circ}$ przy $6\,\mathrm{V}$.
\end{itemize}

Przy napięciu $5\,\mathrm{V}$, 
prędkość wyniesie około:
\begin{equation}
V_{5V}\approx 0{,}20 - \left(\frac{0{,}09}{1{,}2} \cdot 0{,}2\right) \approx 0{,}185\,\mathrm{s}/60^{\circ}
\end{equation}

Jeśli serwo potrzebuje $0{,}185\,\mathrm{s}$ na pokonanie $60^{\circ}$, to jego 
prędkość maksymalna wynosi ok. $324^{\circ}/\mathrm{s}$.

W klasycznym modelu $G(s)=\frac{1}{Ts+1}$, czas odpowiedzi (10\%--90\%) wynosi 
ok. $2{,}2T$. Jeśli przyjąć, że dla małych skoków dynamika jest zbliżona do czasu 
przemieszczenia podanego w specyfikacji. Dla
$6\,\mathrm{V}$($0{,}11\,\mathrm{s}/60^{\circ}$) $T$ mogłoby wynosić ok
$\mathrm{V}$$0{,}05$--$0{,}07\,\mathrm{s}$. Więc dla $5\,\mathrm{V}$
($0{,}185\,\mathrm{s}/60^{\circ}$) $T$ może wynosić $0{,}095\,\mathrm{s}$ .

Ostatecznie dynamika serwa bedzie opisana jako:

\begin{equation}
  G_{\mathrm{serwo}}(s)=\frac{\Theta_{\mathrm{serwo}}(s)}{U(s)}=\frac{1}{T_{\mathrm{serwo}}s+1},
\end{equation}

\subsection{Dynamika piłeczki na belce}

Rozpatrując dynamikę piłeczki na belce, wyprowadza się równanie wiążące kąt belki 
($\theta$) z przyspieszeniem liniowym piłeczki ($\ddot{x}$). 

\subsubsection{II Zasada Dynamiki $F=ma$}

\begin{figure}[H]
  \centering
  
  \caption{Rozkład sił działajacych na kule na równi pochyłej}
\end{figure}

Obserwując siły działające wzdłuż belki:
\begin{itemize}
  \item Grawitacja ($F_g$): Jej składowa równoległa do belki wynosi $m \cdot g \cdot \sin(\theta)$.
  \item Tarcie ($T$): Działa w górę belki i zmusza piłeczkę do obrotu.
\end{itemize}

Równanie Newtona dla ruchu postępowego:
\begin{equation}
m \cdot \ddot{x} = m \cdot g \cdot \sin(\theta) - T
\end{equation}

\subsubsection{II Zasada Dynamiki $M=J\epsilon$}

Moment obrotowy wokół własnej osi piłeczki jest generowany przez siłę tarcia na 
ramieniu promienia $R$(promień piłeczki):
\begin{equation}
T \cdot R = J \cdot \ddot{\alpha}
\end{equation}
gdzie $J$ to moment bezwładności piłeczki, a $\ddot{\alpha}$ to przyspieszenie kątowe.

\subsubsection{Warunek Toczenia bez Poślizgu}

Piłeczka toczy się bez poślizgu, co oznacza, że przyspieszenie liniowe zależy od 
przyspieszenia kątowego:
\begin{equation}
\ddot{x} = \ddot{\alpha} \cdot R \quad \Rightarrow \quad \ddot{\alpha} = \frac{\ddot{x}}{R}
\end{equation}

\subsubsection{Eliminacja Tarcia i Przyspieszenia Kątowego}

Z warunku toczenia bez poślizgu, podstawiając $\ddot{\alpha}$ do równania momentu:
\begin{equation}
T \cdot R = J \cdot \frac{\ddot{x}}{R} \quad \Rightarrow \quad T = \frac{J \cdot \ddot{x}}{R^2}
\end{equation}

Wstawiając to wyrażenie na $T$ do równania ruchu postępowego:
\begin{equation}
m \cdot \ddot{x} = m \cdot g \cdot \sin(\theta) - \frac{J \cdot \ddot{x}}{R^2}
\end{equation}

\subsubsection{Rozwiązanie dla Przyspieszenia Liniowego}

Przenosząc człon z $\ddot{x}$ na lewą stronę:
\begin{equation}
m \cdot \ddot{x} + \frac{J \cdot \ddot{x}}{R^2} = m \cdot g \cdot \sin(\theta)
\end{equation}

Wyciągając $\ddot{x}$ przed nawias:
\begin{equation}
\ddot{x} \left( m + \frac{J}{R^2} \right) = m \cdot g \cdot \sin(\theta)
\end{equation}

Dzieląc przez nawias:
\begin{equation}
\ddot{x} = \frac{m \cdot g \cdot \sin(\theta)}{m + \frac{J}{R^2}}
\end{equation}

Dzieląc licznik i mianownik przez masę $m$:
\begin{equation}
\ddot{x} = \frac{g \cdot \sin(\theta)}{1 + \frac{J}{m R^2}}
\end{equation}

Dla małych kątów $\sin(\theta) \approx \theta$, ostatecznie otrzymuje się:
\begin{equation}
\ddot{x} = \frac{g}{1 + \frac{J}{m R^2}} \cdot \theta
\end{equation}
gdzie współczynnik:
\begin{equation}
\frac{g}{1 + \frac{J}{m R^2}}=c_{\mathrm{ball}}
\end{equation}
ostatecznie:
\begin{equation}
\ddot{x}=c_{\mathrm{ball}} \cdot \theta
\end{equation}

\subsubsection{Paramter $c_{\mathrm{ball}}$}

\begin{equation}
c_{\mathrm{ball}} = \frac{g}{1 + \frac{J}{m R^2}}
\end{equation}

Moment bezwładności: $J = \frac{2}{3} m R^2$. 
Podstawiając do mianownika:
\begin{equation}
1 + \frac{\frac{2}{3} m R^2}{m R^2} = 1 + \frac{2}{3} = \frac{5}{3} \approx 1{,}667
\end{equation}

Współczynnik:
\begin{equation}
c_{\mathrm{ball}} = \frac{g}{1{,}667} = \frac{3}{5} g = 0{,}6 \, g
\end{equation}

Stała $c_{\mathrm{ball}}$ wyznaczająca dynamikę piłeczki wynosi:
\begin{equation}
c_{\mathrm{ball}} = 0{,}6 \cdot 9{,}81 = 5{,}886 \, \mathrm{m/s^2}
\end{equation}

\subsubsection{Transmitancja piłeczki na belce}

Równanie dynamiki piłeczki w dziedzinie czasu jest następujące:
\begin{equation}
\ddot{x}=c_{\mathrm{ball}} \cdot \theta
\end{equation}

Stosując transformatę Laplace'a. Dla warunków początkowych ($x(0) = 0$, $\dot{x}(0) = 0$, $\theta(0) = 0$):
\begin{equation}
\mathcal{L}\{\ddot{x}(t)\} = s^2 \cdot X(s)
\end{equation}
\begin{equation}
\mathcal{L}\{\theta(t)\} = \Theta(s)
\end{equation}

\begin{equation}
s^2 \cdot X(s) = c_{\mathrm{ball}} \cdot \Theta(s)
\end{equation}

\paragraph{Wyznaczenie Transmitancji:}

Transmitancja jest definiowana jako stosunek transformaty Laplace'a wyjścia do 
transformaty Laplace'a wejścia (przy zerowych warunkach początkowych):
\begin{equation}
G_{\mathrm{ball}}(s) = \frac{X(s)}{\Theta_{\mathrm{beam}}(s)}=\frac{c_{\mathrm{ball}}}{s^2}
\end{equation}

\subsection{Transmitancja całego układu}

Posiadając kompletny zestaw opisu dynamik elementów układu, można teraz połączyć 
transmitancję serwa z transmitancją piłeczki na belce, uwzględniając mechaniczne 
połączenie między nimi.

\subsubsection{Zależnośc pomiedzy $\Theta_{serwo}$ i $\Theta_{beam}$}

\begin{figure}[H]
  \centering
  
  \caption{fizyczne mechaniczne połączenie pomiedzy serwem i belką}
\end{figure}
 
Zakładając idealne połączenie pomiedzy serwem i belką, obowiązuje 
następująca zależność kinematyczna:

\begin{equation}
r_{\mathrm{serwo}} \cdot \theta_{\mathrm{serwo}} = r_{\mathrm{belka}} \cdot \theta_{\mathrm{belka}}
\end{equation}

gdzie:
\begin{itemize}
  \item $r_{\mathrm{serwo}}$ -- promień dźwigni na wale serwa($3\,\mathrm{cm}$),
  \item $r_{\mathrm{belka}}$ -- promień dźwigni na wale belki($15\,\mathrm{cm}$),
\end{itemize}

Stąd wynika relacja kątów:

\begin{equation}
\theta_{\mathrm{belka}} = \frac{r_{\mathrm{serwo}}}{r_{\mathrm{belka}}} \cdot \theta_{\mathrm{serwo}} = k_{mech} \cdot \theta_{\mathrm{serwo}}
\end{equation}

Gdzie $k_{mech}$ jest przekładnią mechaniczna.

\subsubsection{Połączenie Szeregowe Transmitancji}

Układ składa się z dwóch elementów połączonych szeregowo:
\begin{itemize}
  \item Serwo: $G_{\mathrm{serwo}}(s) = \frac{\Theta_{\mathrm{serwo}}(s)}{U(s)} = \frac{1}{T_{\mathrm{serwo}} s + 1}$
  \item Piłeczka na belce: $G_{\mathrm{ball}}(s) = \frac{X(s)}{\Theta_{\mathrm{belka}}(s)} = \frac{c_{\mathrm{ball}}}{s^2}$
\end{itemize}

Dla połączenia szeregowego bez sprzężeń zwrotnych, ścieżka sygnału przebiega:

\begin{equation}
U(s) \xrightarrow{G_{\mathrm{serwo}}} \Theta_{\mathrm{serwo}}(s) \xrightarrow{k_{mech}} \Theta_{\mathrm{belka}}(s) \xrightarrow{G_{\mathrm{ball}}} X(s)
\end{equation}

Transmitancja piłeczki wynosi:
\begin{equation}
G_{\mathrm{ball}}(s) = \frac{X(s)}{\Theta_{\mathrm{belka}}(s)}
\end{equation}

 Należy podstawić 
relację $\Theta_{\mathrm{belka}}(s) = k_{\mathrm{mech}} \cdot \Theta_{\mathrm{serwo}}(s)$:

\begin{equation}
G_{\mathrm{ball}}(s) = \frac{X(s)}{\Theta_{\mathrm{belka}}(s)} = \frac{X(s)}{k_{\mathrm{mech}} \cdot \Theta_{\mathrm{serwo}}(s)} 
\end{equation}

Stąd wynika:
\begin{equation}
X(s) = k_{\mathrm{mech}h} \cdot G_{\mathrm{ball}}(s) \cdot \Theta_{\mathrm{serwo}}(s)
\end{equation}

Teraz, znając że $\Theta_{\mathrm{serwo}}(s) = G_{\mathrm{serwo}}(s) \cdot U(s)$, otrzymuje się:

\begin{equation}
X(s) = k_{\mathrm{mech}} \cdot G_{\mathrm{ball}}(s) \cdot G_{\mathrm{serwo}}(s) \cdot U(s)
\end{equation}

Stąd transmitancja całkowita:

\begin{equation}
G_{\mathrm{total}}(s) = \frac{X(s)}{U(s)} = k_{\mathrm{mech}} \cdot G_{\mathrm{ball}}(s) \cdot G_{\mathrm{serwo}}(s)
\end{equation}

Podstawiając transmitancje:

\begin{equation}
G_{\mathrm{total}}(s) = k_{\mathrm{mech}} \cdot \frac{c_{\mathrm{ball}}}{s^2} \cdot \frac{1}{T_{\mathrm{serwo}} s + 1}
\end{equation}

\subsubsection{Ostateczna Forma Transmitancji Całego Układu}

\begin{equation}
G_{\mathrm{total}}(s) =\frac{k_{\mathrm{mech}} \cdot c_{\mathrm{ball}}}{s^2 \cdot (T_{\mathrm{serwo}} s + 1)}
\end{equation}

Rozwijając mianownik:

\begin{equation}
G_{\mathrm{total}}(s) = \frac{k_{\mathrm{mech}} \cdot c_{\mathrm{ball}}}{T_{\mathrm{serwo}} s^3 + s^2}
\end{equation}

Gdzie:
\begin{itemize}
  \item $k_{\mathrm{mech}}=\frac{3cm}{15cm}=0,2$
  \item $c_{\mathrm{ball}}=5,586$
  \item $T_{\mathrm{serwo}}=0.095$
\end{itemize}

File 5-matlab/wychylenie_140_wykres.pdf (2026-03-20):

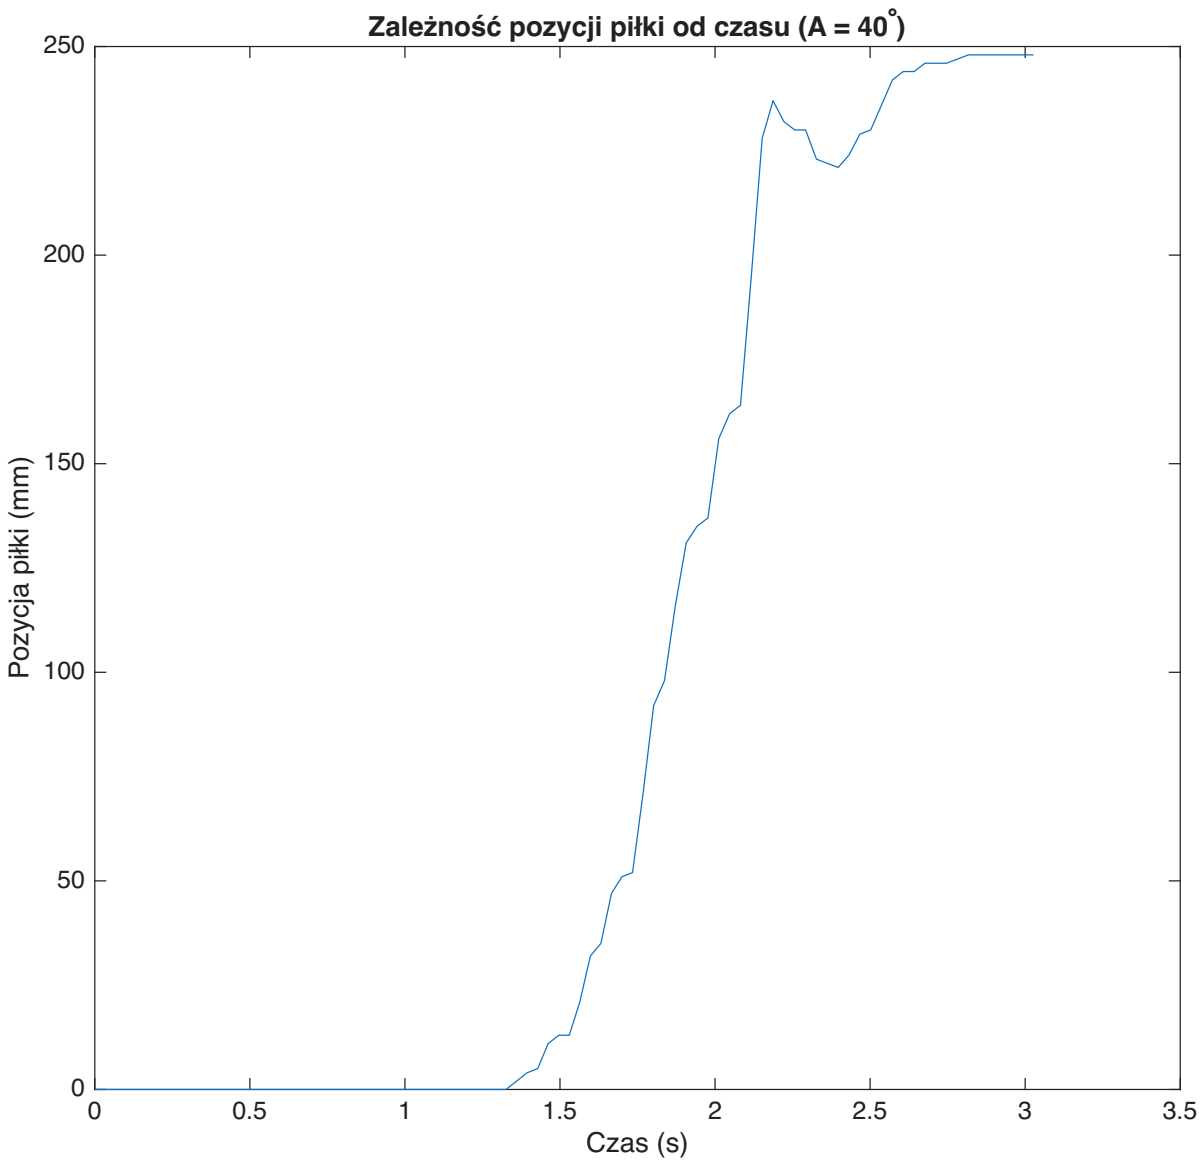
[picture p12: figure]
Pozycja piłki (mm); ale; ji pił

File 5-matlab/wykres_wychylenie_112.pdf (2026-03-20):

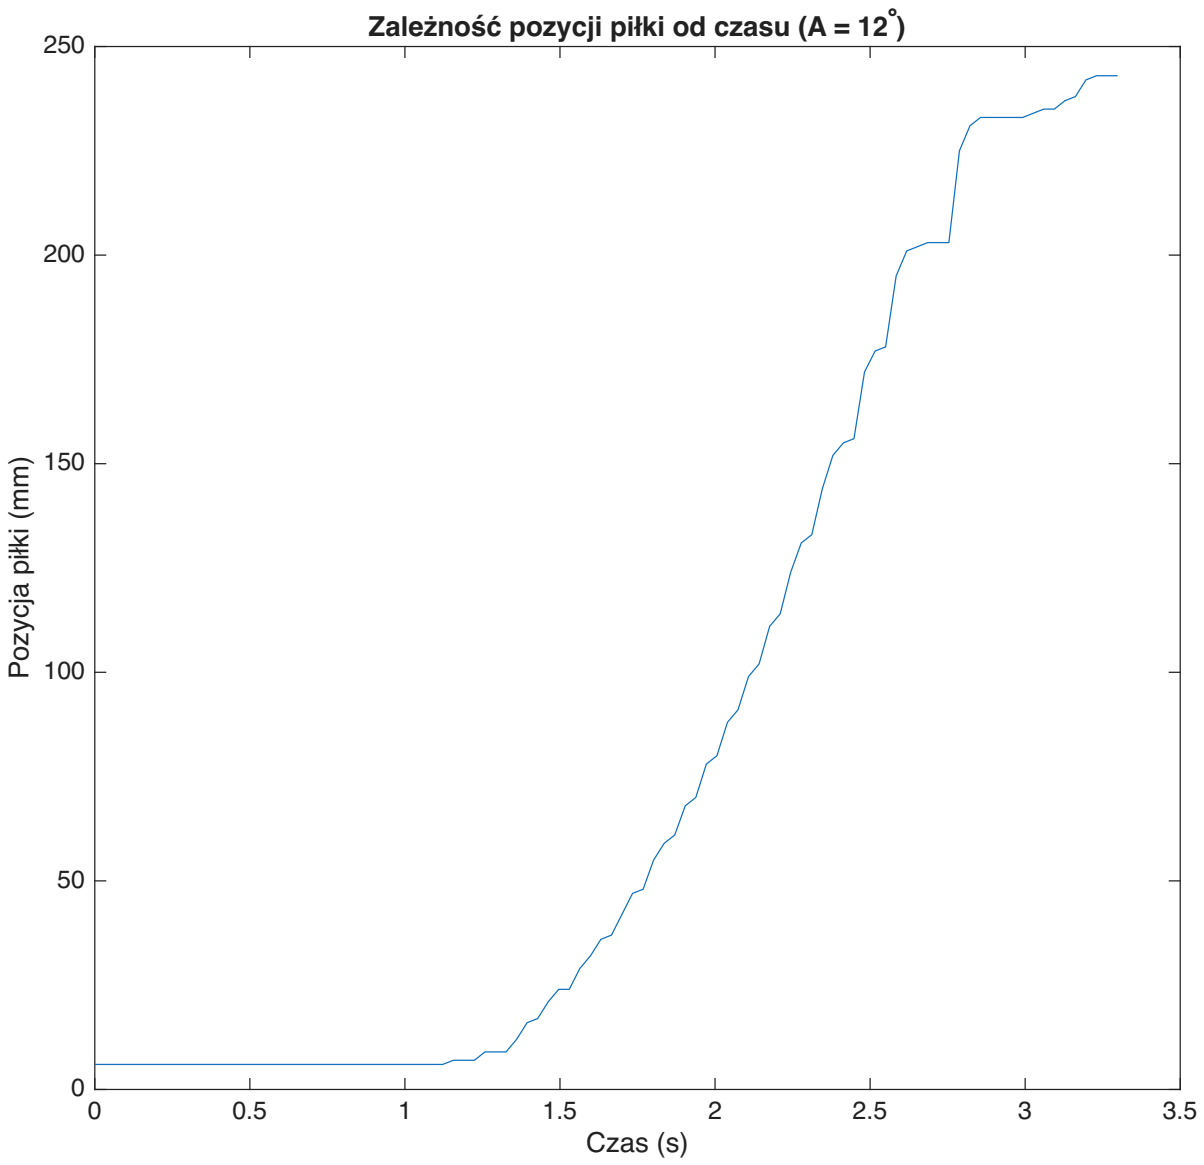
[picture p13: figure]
Pozycja piłki (mm); ale; ji pił

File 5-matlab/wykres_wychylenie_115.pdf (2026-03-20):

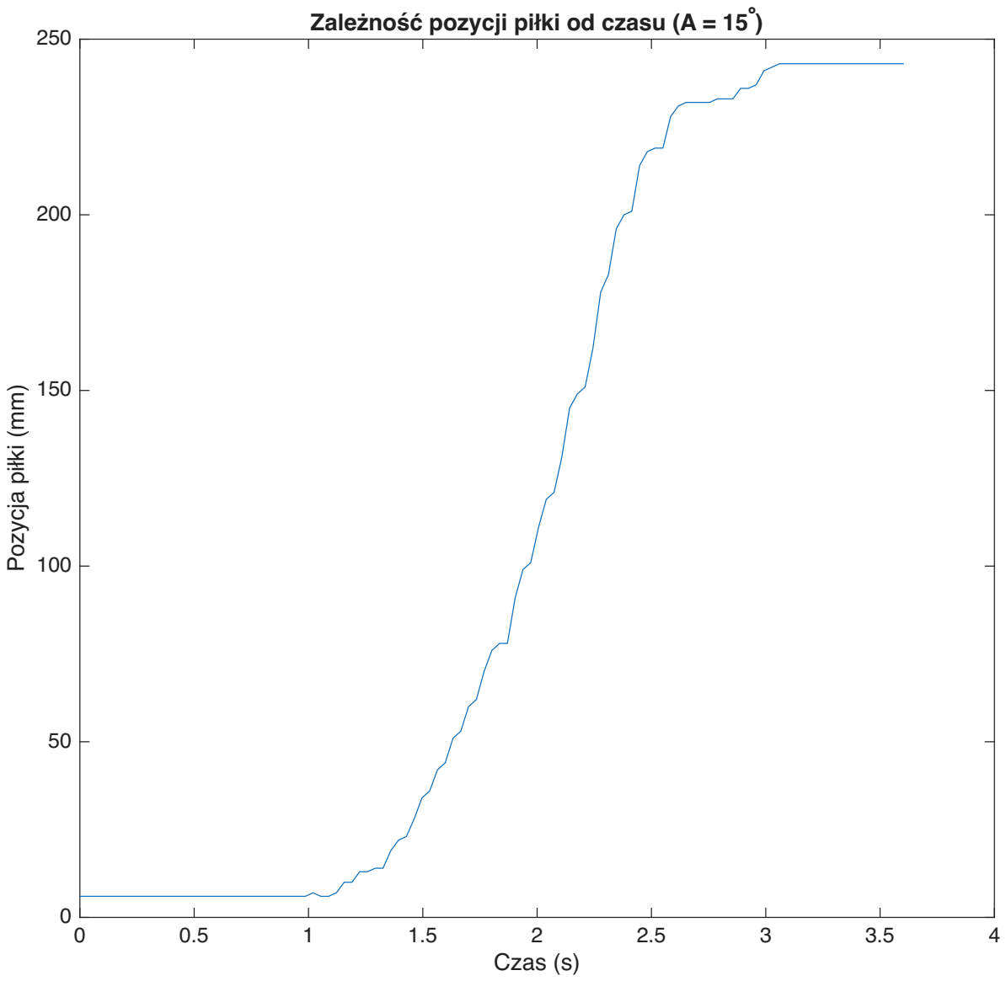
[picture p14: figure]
Pozycja piłki (mm); ale; ji pił

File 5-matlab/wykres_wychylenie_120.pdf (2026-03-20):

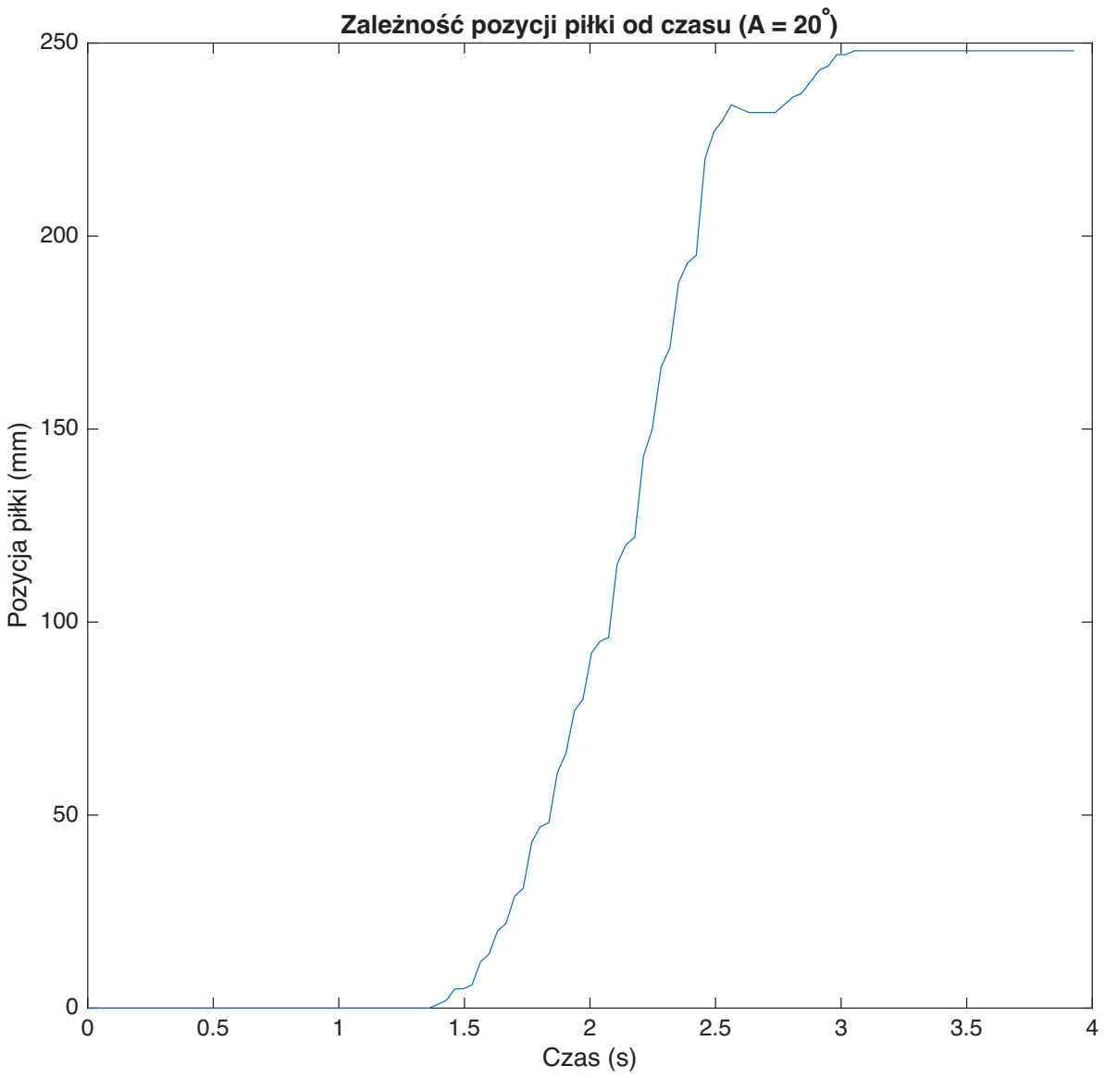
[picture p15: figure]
Pozycja piłki (mm); ale; ji pił

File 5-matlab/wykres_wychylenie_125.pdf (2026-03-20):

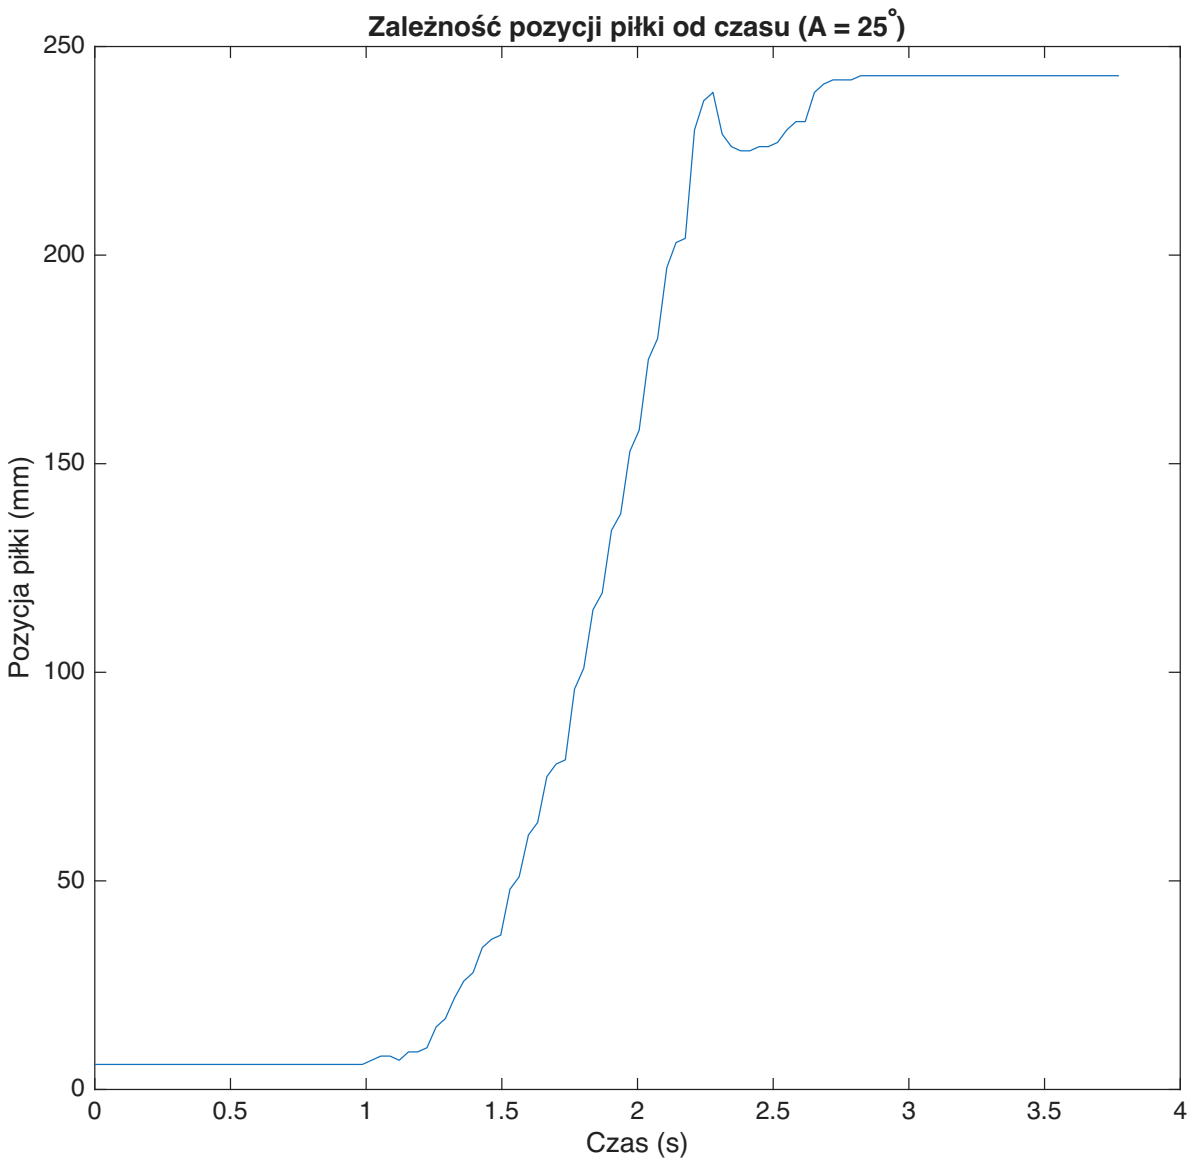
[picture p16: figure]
Pozycja piłki (mm); ale; ji pił

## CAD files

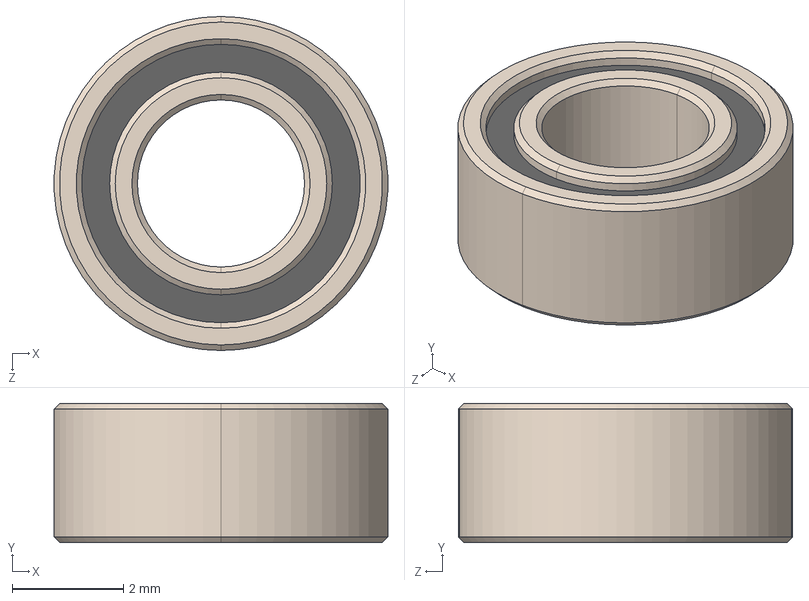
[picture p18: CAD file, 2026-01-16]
4-cad/bearing/MR63-2RS Thrus Bearing- Thinhhouy.STEP
5.99 x 2.50 x 6.00 mm

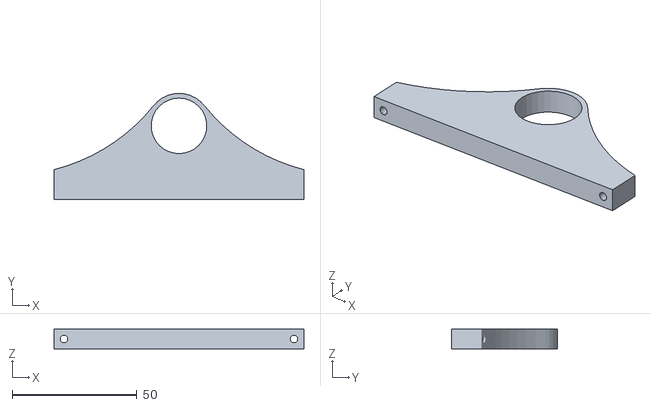
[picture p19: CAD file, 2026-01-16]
4-cad/filesforprint/podstawa.stl
100.0 x 42.5 x 8.00

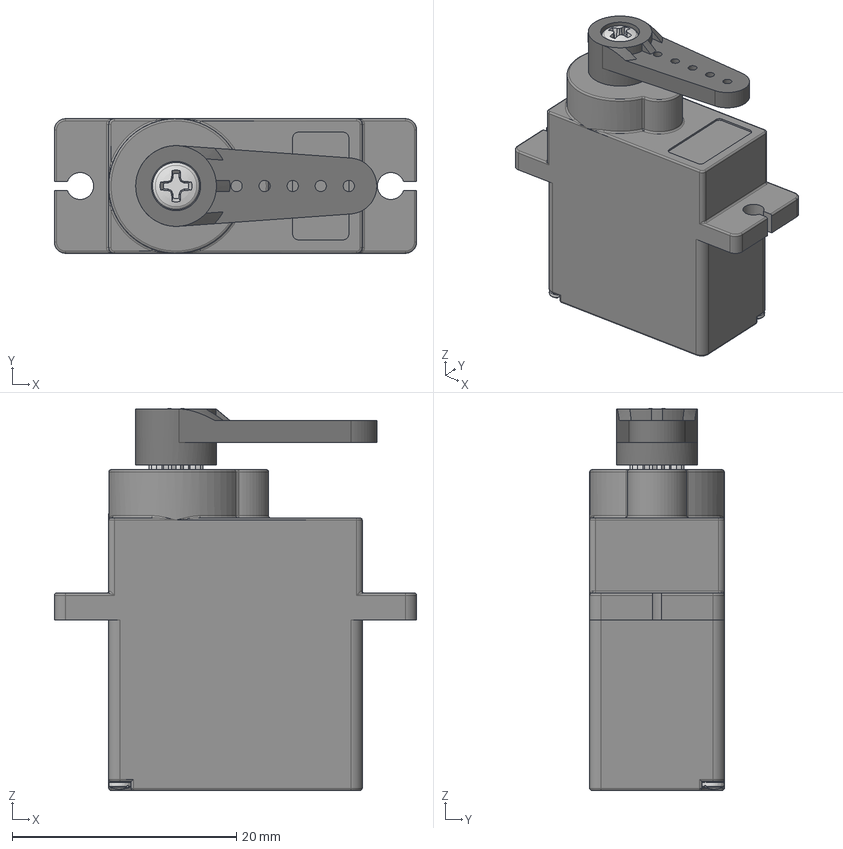
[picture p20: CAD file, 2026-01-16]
4-cad/mg90s-micro-servo-motor-1/MG90S Micro Servo Motor/MG90S Micro Servo Motor.step
32.3 x 12.0 x 34.1 mm
Shaft
Horn
Screw

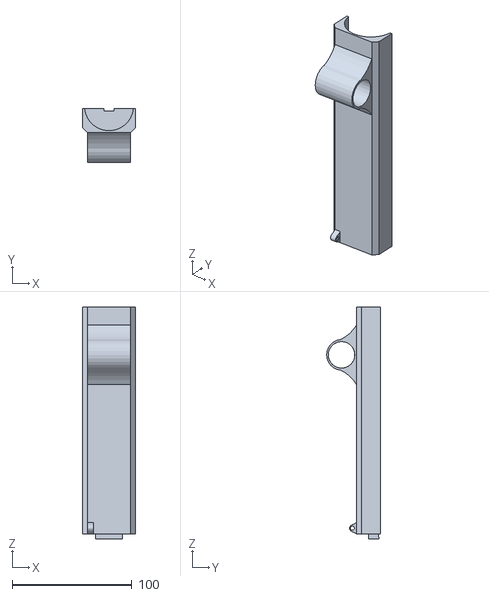
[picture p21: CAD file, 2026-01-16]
4-cad/filesforprint/rampwloop.stl
44.0 x 45.0 x 194.0

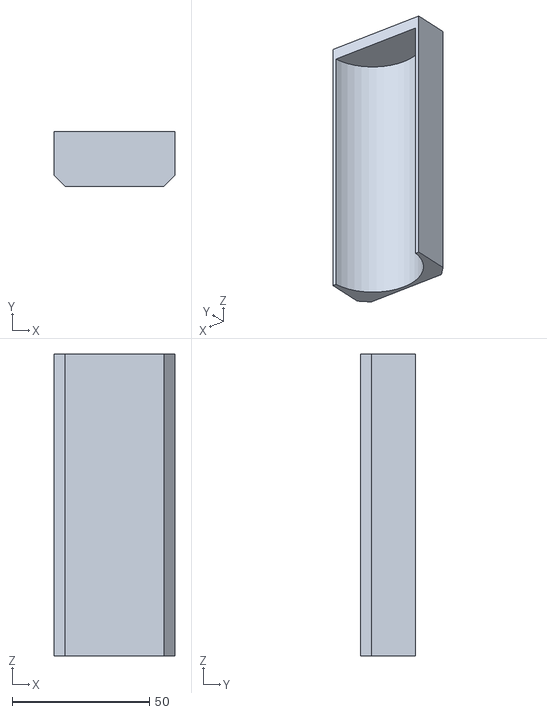
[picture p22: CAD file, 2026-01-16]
4-cad/filesforprint/rampawoloop.stl
44.0 x 20.0 x 110.0

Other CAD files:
4-cad/Grove - Time of Flight Distance Sensor (VL53L0X)/202002000_PCBA;Grove - Time of Flight Distance Sensor (VL53L0X)_原理图/Grove-Time-of-Flight-Distance-SensorVL53L0X/Grove.iam
4-cad/Grove - Time of Flight Distance Sensor (VL53L0X)/202002000_PCBA;Grove - Time of Flight Distance Sensor (VL53L0X)_原理图/Grove-Time-of-Flight-Distance-SensorVL53L0X/Grove.ipt
4-cad/Grove - Time of Flight Distance Sensor (VL53L0X)/202002000_PCBA;Grove - Time of Flight Distance Sensor (VL53L0X)_原理图/Grove-Time-of-Flight-Distance-SensorVL53L0X/Grove_1.ipt
4-cad/Grove - Time of Flight Distance Sensor (VL53L0X)/202002000_PCBA;Grove - Time of Flight Distance Sensor (VL53L0X)_原理图/Grove-Time-of-Flight-Distance-SensorVL53L0X/Grove_10.ipt
4-cad/Grove - Time of Flight Distance Sensor (VL53L0X)/202002000_PCBA;Grove - Time of Flight Distance Sensor (VL53L0X)_原理图/Grove-Time-of-Flight-Distance-SensorVL53L0X/Grove_11.ipt
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

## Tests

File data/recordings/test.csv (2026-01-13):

time | distance | filtered | setpoint | error | control
0.0051 | 124.0 | 123.0 | 125.0 | 1.0 | 103.0
0.0366 | 125.0 | 124.0 | 125.0 | 0.0 | 102.0
0.0927 | 125.0 | 124.0 | 125.0 | 0.0 | 102.0
0.1108 | 125.0 | 124.0 | 125.0 | 0.0 | 102.0
0.147 | 125.0 | 124.0 | 125.0 | 0.0 | 103.0
0.2005 | 125.0 | 124.0 | 125.0 | 0.0 | 103.0
0.2186 | 124.0 | 124.0 | 125.0 | 0.0 | 104.0
0.2561 | 124.0 | 124.0 | 125.0 | 0.0 | 105.0
0.3121 | 125.0 | 124.0 | 125.0 | 0.0 | 103.0
0.3292 | 125.0 | 124.0 | 125.0 | 0.0 | 103.0
0.3535 | 125.0 | 124.0 | 125.0 | 0.0 | 103.0
0.4218 | 125.0 | 124.0 | 125.0 | 0.0 | 103.0
0.4388 | 124.0 | 124.0 | 125.0 | 0.0 | 104.0
0.4615 | 124.0 | 124.0 | 125.0 | 0.0 | 105.0
0.5325 | 124.0 | 124.0 | 125.0 | 0.0 | 104.0
0.5501 | 125.0 | 124.0 | 125.0 | 0.0 | 103.0
0.5695 | 125.0 | 124.0 | 125.0 | 0.0 | 103.0
0.6395 | 125.0 | 124.0 | 125.0 | 0.0 | 103.0
0.6572 | 123.0 | 123.0 | 125.0 | 1.0 | 105.0
0.6775 | 123.0 | 123.0 | 125.0 | 1.0 | 106.0
0.7447 | 123.0 | 123.0 | 125.0 | 1.0 | 106.0
0.765 | 124.0 | 123.0 | 125.0 | 1.0 | 104.0
0.7867 | 125.0 | 124.0 | 125.0 | 0.0 | 102.0
0.8217 | 125.0 | 124.0 | 125.0 | 0.0 | 102.0
0.8665 | 123.0 | 123.0 | 125.0 | 1.0 | 104.0
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

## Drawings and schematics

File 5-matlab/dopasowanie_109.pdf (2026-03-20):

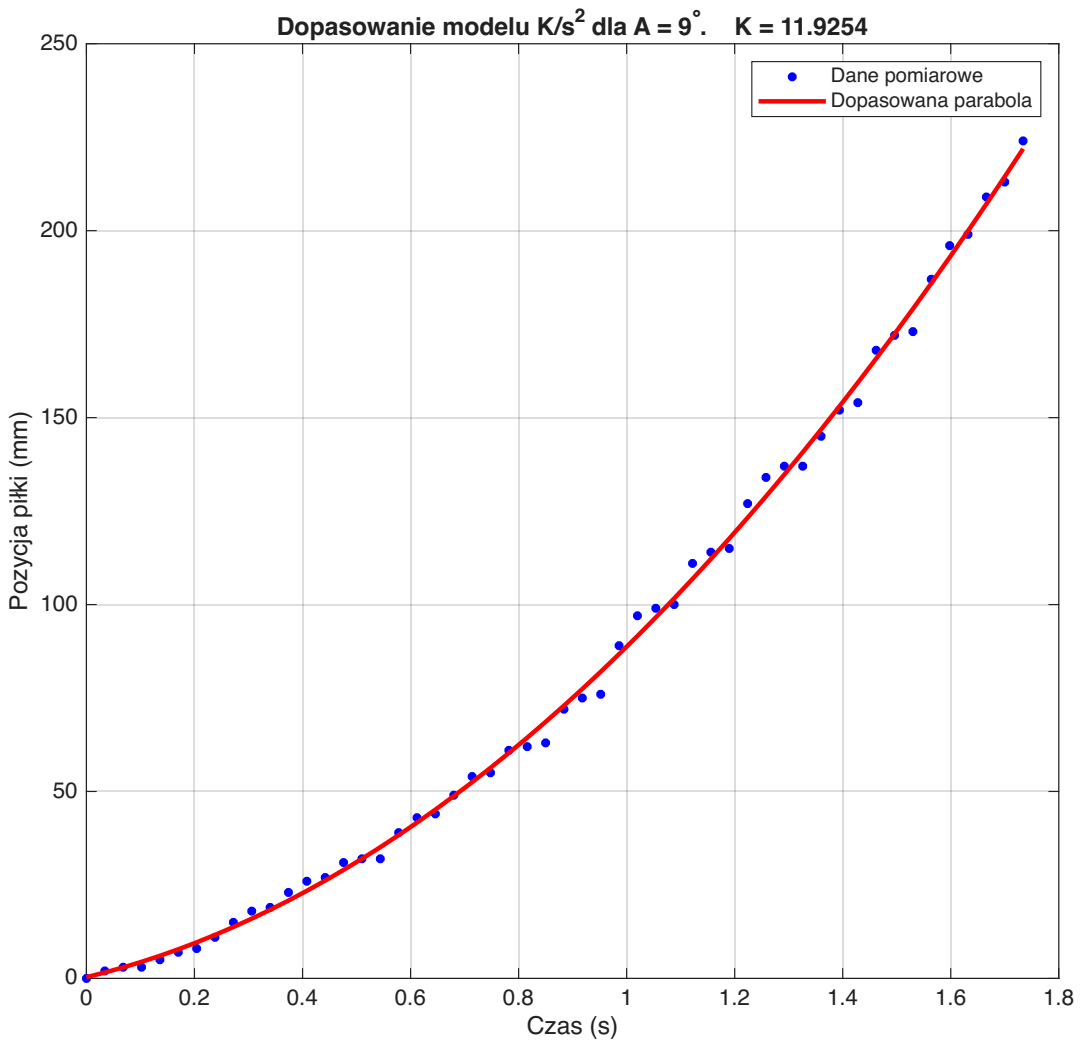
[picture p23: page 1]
nie; elu; dla; mia; ola

Pozycja piłki (mm)

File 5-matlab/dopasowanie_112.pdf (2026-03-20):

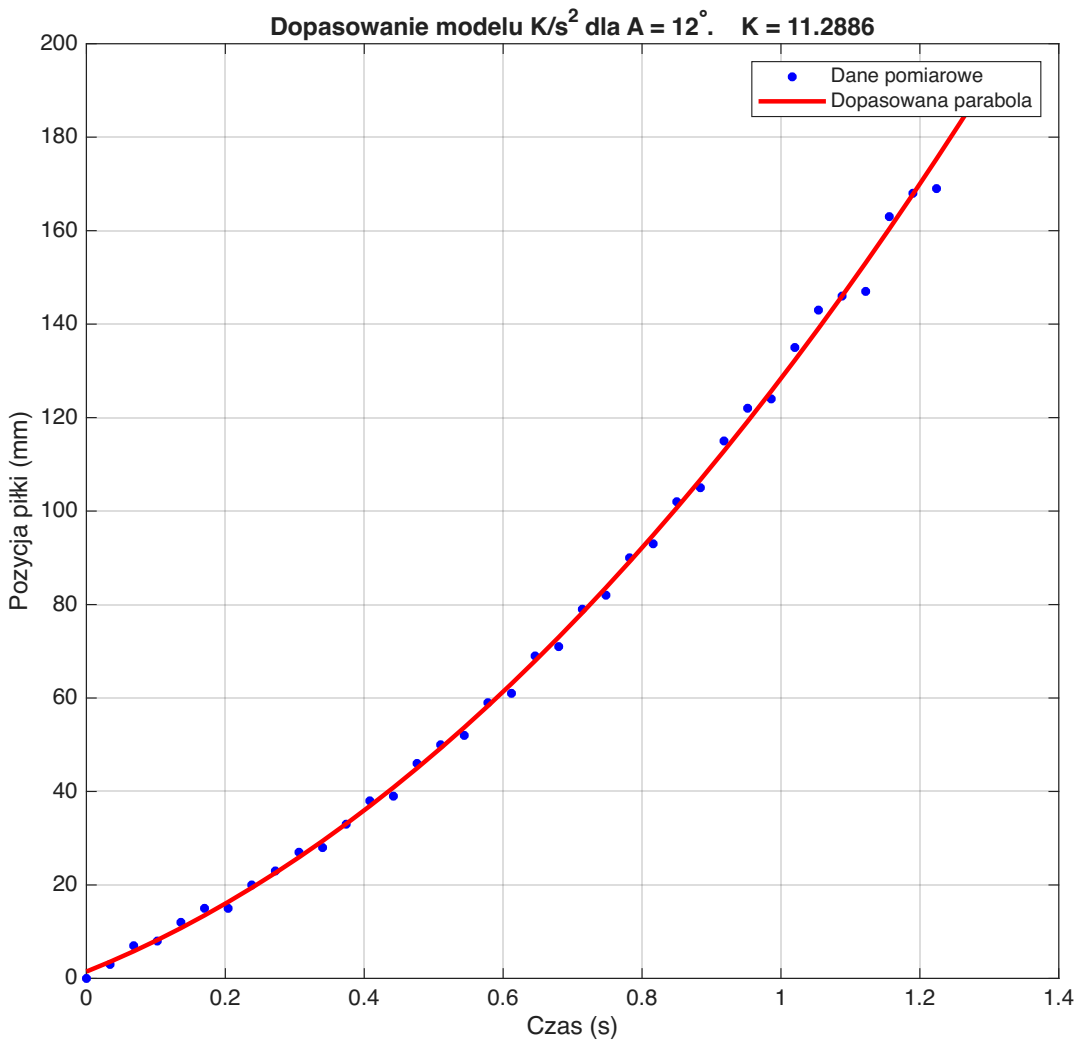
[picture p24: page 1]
nie; elu; dla; mia; ola

Pozycja piłki (mm)

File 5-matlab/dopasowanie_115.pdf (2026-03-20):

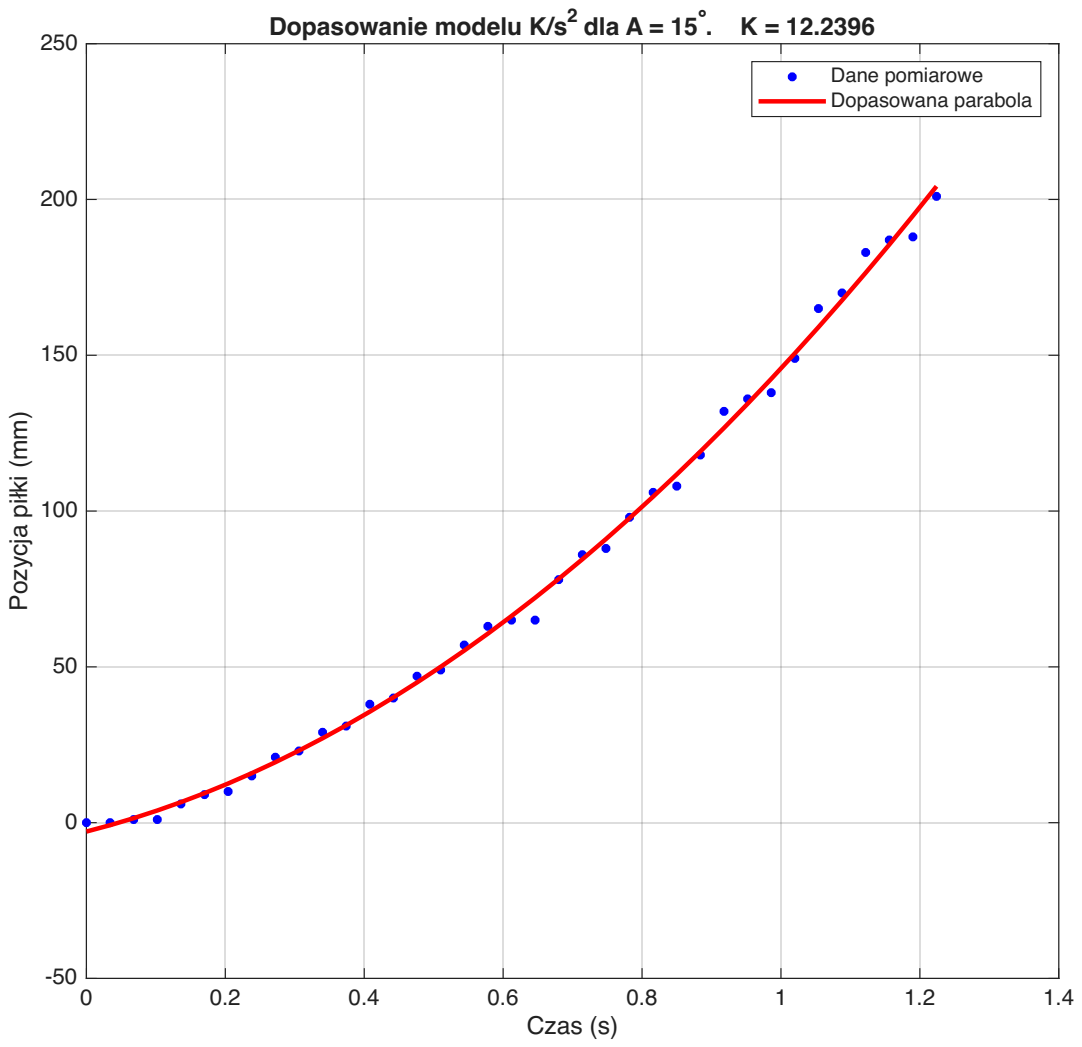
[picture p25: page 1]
nie; elu; dla; mia; ola

Pozycja piłki (mm)

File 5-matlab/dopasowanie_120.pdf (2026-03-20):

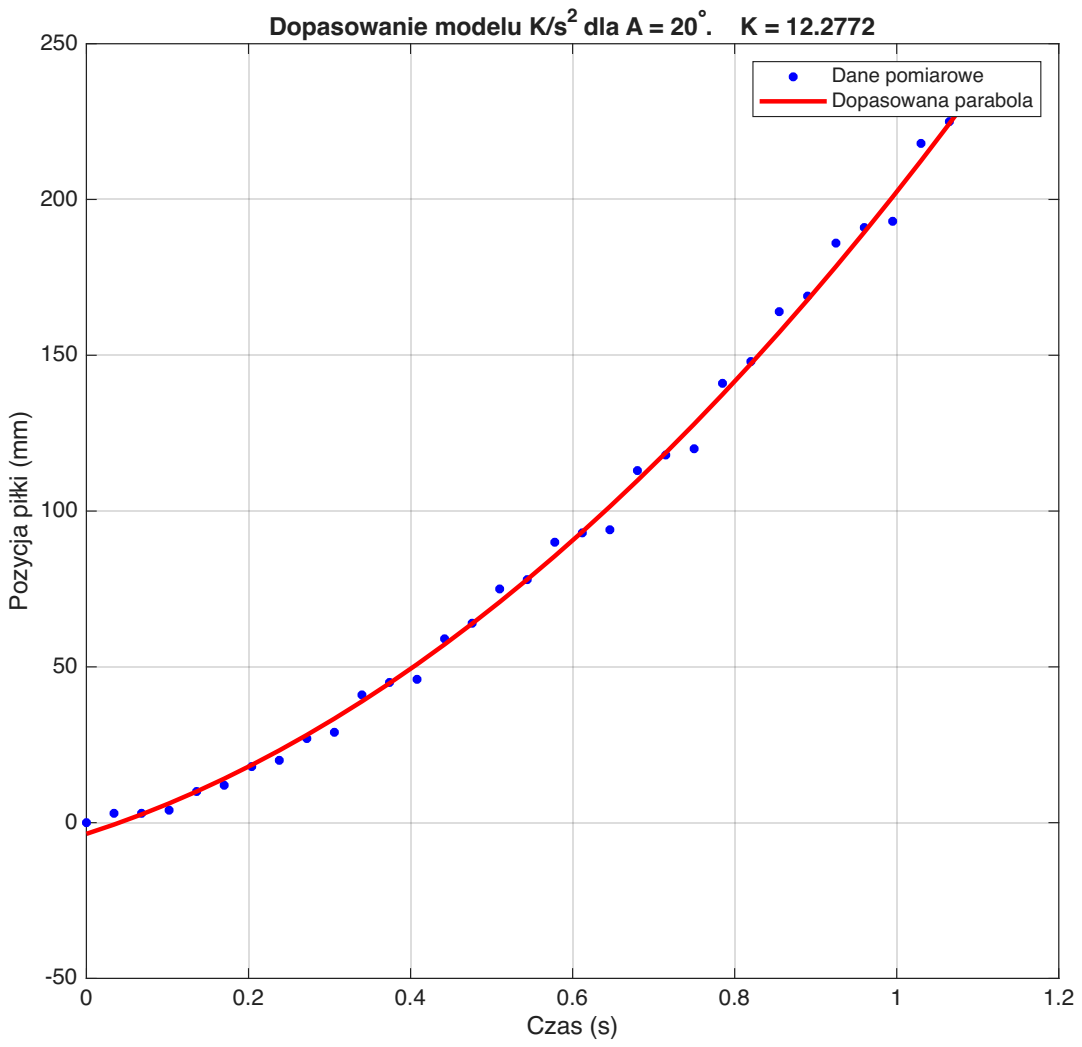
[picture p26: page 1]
nie; elu; dla; mia; ola

Pozycja piłki (mm)

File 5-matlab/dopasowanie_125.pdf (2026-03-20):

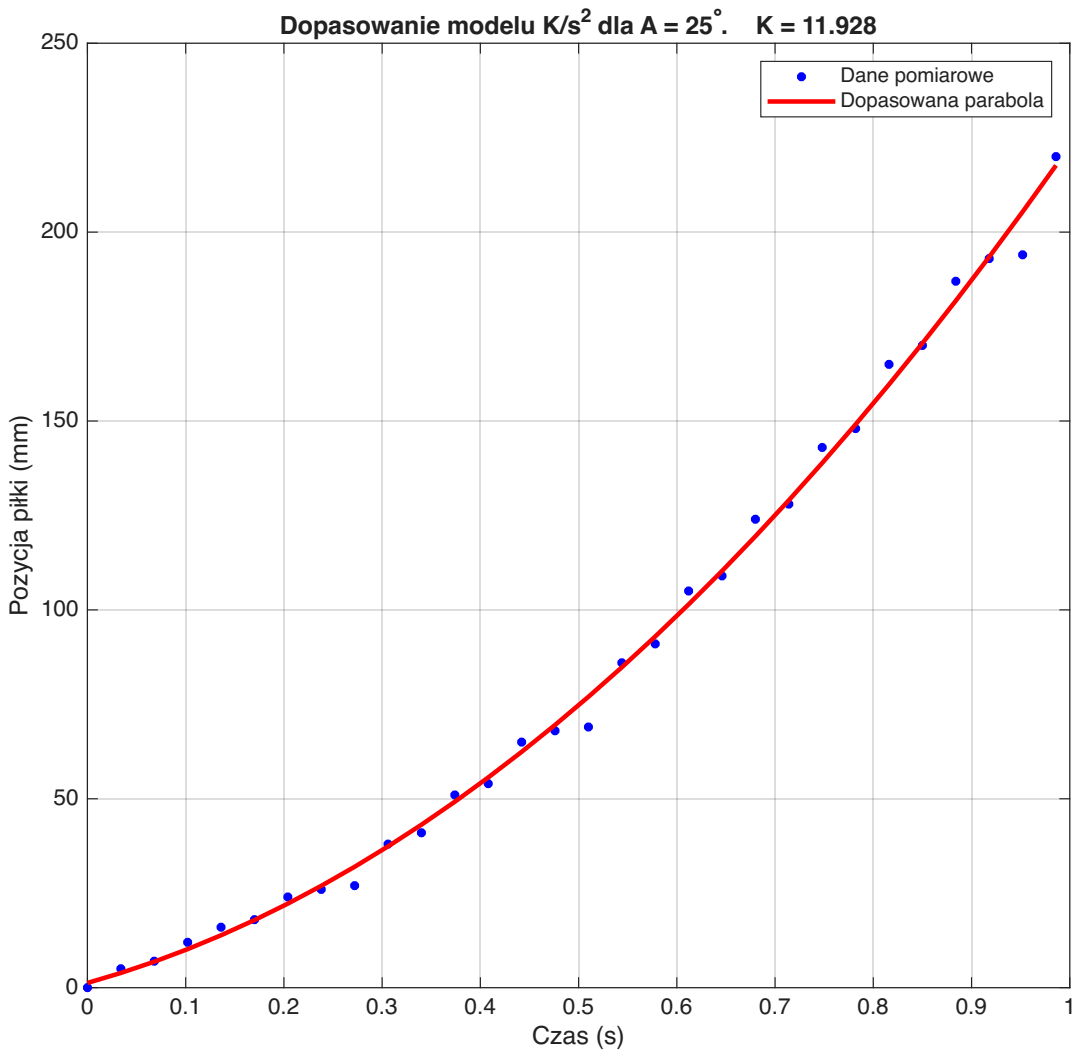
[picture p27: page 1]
nie; elu; dla; mia; ola

Pozycja piłki (mm)

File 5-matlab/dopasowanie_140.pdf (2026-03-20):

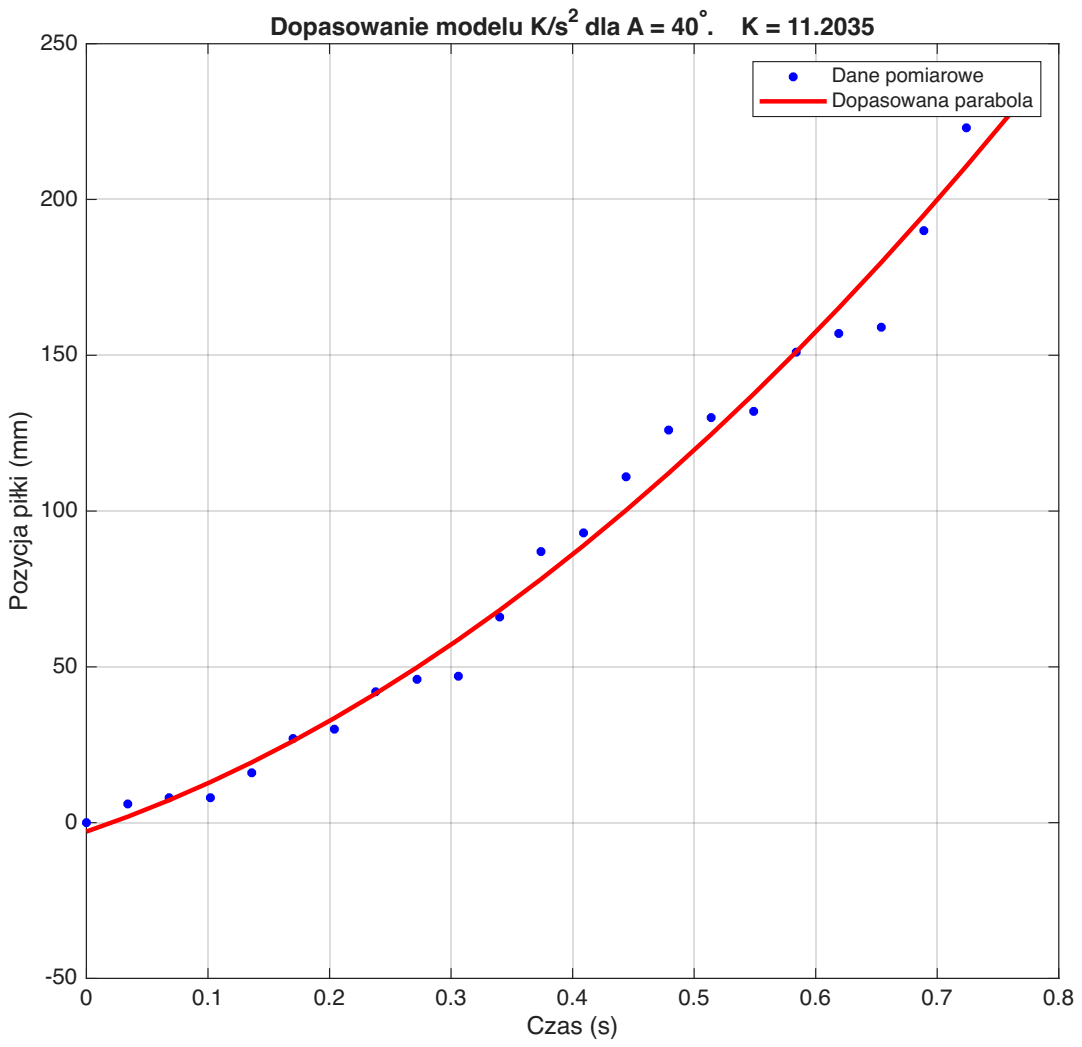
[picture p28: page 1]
nie; elu; dla; mia; ola

Pozycja piłki (mm)

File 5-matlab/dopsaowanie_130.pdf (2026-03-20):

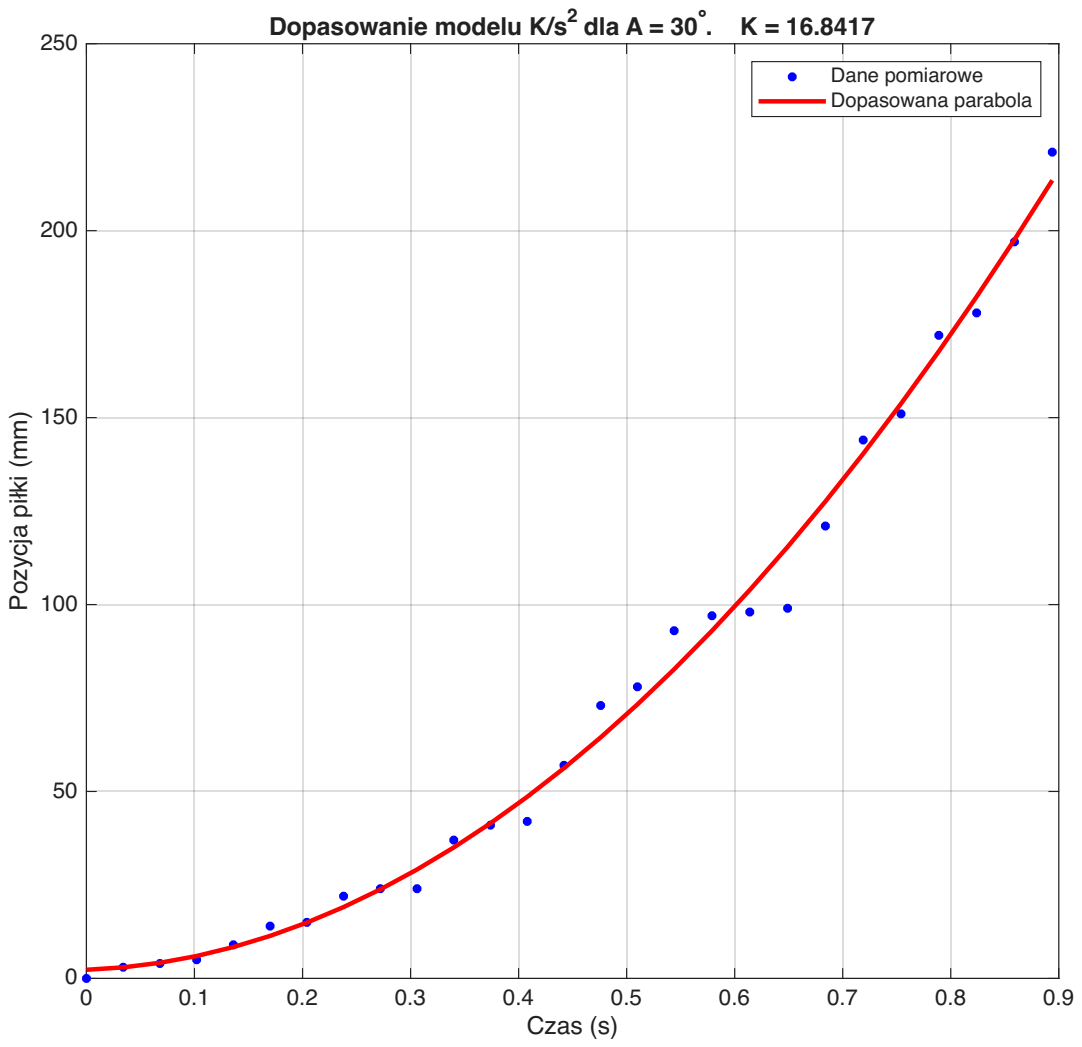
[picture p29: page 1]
nie; elu; dla; mia; ola

Pozycja piłki (mm)

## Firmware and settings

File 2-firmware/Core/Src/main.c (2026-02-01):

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
/* Includes ------------------------------------------------------------------*/
#include "main.h"
#include "string.h"
#include "cmsis_os.h"

/* USER CODE BEGIN Includes */

#include "VL53L0X.h"
#include <stdio.h>
#include <stdlib.h>
#include <math.h>
#include "filters.h"
#include "calibration.h"
#include "servo_pid.h"
#include "lqr.h"
#include "crc8.h"
#include "leds.h"

/* USER CODE END Includes */

#if defined ( __ICCARM__ ) /*!< IAR Compiler */
#pragma location=0x2007c000
ETH_DMADescTypeDef  DMARxDscrTab[ETH_RX_DESC_CNT]; /* Ethernet Rx DMA Descriptors */
#pragma location=0x2007c0a0
ETH_DMADescTypeDef  DMATxDscrTab[ETH_TX_DESC_CNT]; /* Ethernet Tx DMA Descriptors */

#elif defined ( __CC_ARM )  /* MDK ARM Compiler */

__attribute__((at(0x2007c000))) ETH_DMADescTypeDef  DMARxDscrTab[ETH_RX_DESC_CNT]; /* Ethernet Rx DMA Descriptors */
__attribute__((at(0x2007c0a0))) ETH_DMADescTypeDef  DMATxDscrTab[ETH_TX_DESC_CNT]; /* Ethernet Tx DMA Descriptors */

#elif defined ( __GNUC__ ) /* GNU Compiler */

ETH_DMADescTypeDef DMARxDscrTab[ETH_RX_DESC_CNT] __attribute__((section(".RxDecripSection"))); /* Ethernet Rx DMA Descriptors */
ETH_DMADescTypeDef DMATxDscrTab[ETH_TX_DESC_CNT] __attribute__((section(".TxDecripSection"))); /* Ethernet Tx DMA Descriptors */
#endif

ETH_TxPacketConfig TxConfig;

ADC_HandleTypeDef hadc1;

ETH_HandleTypeDef heth;

I2C_HandleTypeDef hi2c1;

TIM_HandleTypeDef htim3;

UART_HandleTypeDef huart3;
DMA_HandleTypeDef hdma_usart3_rx;
DMA_HandleTypeDef hdma_usart3_tx;

PCD_HandleTypeDef hpcd_USB_OTG_FS;

osThreadId defaultTaskHandle;
osThreadId ControlTaskHandle;
/* USER CODE BEGIN PV */
uint16_t distance;
char msg[64];

// --- DMA UART RX ---
#define DMA_RX_BUFFER_SIZE 128
uint8_t dma_rx_buffer[DMA_RX_BUFFER_SIZE];
volatile uint16_t dma_rx_head = 0;  // Wskaźnik przetwarzania

// Bufor na komendy/ramki
uint8_t cmd_buffer[64];
volatile uint8_t cmd_len = 0;
volatile uint8_t cmd_received = 0;

// Dane z systemu wizyjnego (Python)
volatile float g_vision_ball_pos = 125.0f;   // Pozycja piłeczki [mm] z OpenCV
volatile float g_vision_beam_angle = 0.0f;   // Kąt belki [stopnie] z OpenCV
volatile uint8_t g_vision_data_valid = 0;    // Flaga: czy dane są aktualne
volatile uint32_t g_vision_last_update = 0;  // Timestamp ostatniej aktualizacji

// Stare zmienne obsługi UART (do usunięcia po pełnej migracji)
uint8_t rx_byte;
uint8_t rx_buffer[64];
volatile uint8_t rx_idx = 0;

// Główne zmienne sterujące
volatile float g_setpoint = 125.0f;
volatile float g_Kp = 0.26f;
volatile float g_Ki = 0.0064f;
volatile float g_Kd = 4.4f;

// Zmienne kalibracji
// volatile uint8_t calibration_mode = 0;
// volatile float cal_raw_min = 9999.0f;
// volatile float cal_raw_max = 0.0f;
// volatile uint32_t cal_start_time = 0;

// // Domyślne punkty kalibracyjne
// volatile float sensor_min = 50.0f;
// volatile float sensor_max = 220.0f;
// volatile float sensor_middle = 115.0f;

// Bufor średniego uchybu
float err_buffer[AVG_ERR_SAMPLES];
uint8_t err_idx = 0;
float err_sum = 0.0f;

// Tryb sterowania: 0 = GUI (Manual), 1 = Analog (Potencjometr)
volatile uint8_t control_mode = 0;

// Start/Stop regulatora: 0 = wyłączony, 1 = włączony (domyślnie)
volatile uint8_t g_regulator_enabled = 1;

// Kontroler ServoPID (nasza implementacja) - domyślny
ServoPID_Controller g_servo_pid;

// Kontroler LQR (model 3-stanowy)
LQR_Controller_t g_lqr_ctrl;
volatile float g_K1 = 1.00f;
volatile float g_K2 = 0.75f;
volatile float g_K3 = 0.38f;

// Tryb regulacji: 0 = Custom PID (servo_pid, domyślny), 1 = LQR
volatile uint8_t g_pid_mode = 0;

// Debugging
volatile uint32_t g_adc_raw = 0;
volatile float g_pot_setpoint = 0.0f;

// Zmienna współdzielona do wizualizacji błędu na LED
volatile float g_current_error = 0.0f;

// Manual control angle (when regulator is disabled) - in DEGREES
volatile float g_manual_servo_angle_deg = SERVO_CENTER_DEG;

#include "signal.h" // Generated by Matlab

// --- ID TEST VARIABLES ---
volatile uint8_t g_test_running = 0;
volatile uint32_t g_test_index = 0;

// Sampling period (ms) - can be changed via UART command T:xx
volatile uint32_t g_pid_dt_ms = PID_DT_MS;

/* USER CODE END PV */

void SystemClock_Config(void);
static void MX_GPIO_Init(void);
static void MX_DMA_Init(void);
static void MX_ETH_Init(void);
static void MX_USART3_UART_Init(void);
static void MX_USB_OTG_FS_PCD_Init(void);
static void MX_TIM3_Init(void);
static void MX_I2C1_Init(void);
static void MX_ADC1_Init(void);
void StartDefaultTask(void const *argument);
void StartControlTask(void const *argument);

/* USER CODE BEGIN PFP */

void SetServoAngleDeg(float degrees);
void SetServoAngleSmoothDeg(float target_deg);
extern float g_current_hw_angle_deg;
// Funkcje PID, CRC8, LEDs przeniesione do osobnych modułów

/* USER CODE END PFP */

/* USER CODE BEGIN 0 */

// --- Funkcje DMA UART (bez przerwań na każdy bajt) ---
// Parsowanie ramki wizyjnej: "V:125.5;B:2.3;C:XX\n"
// V = pozycja piłeczki [mm], B = kąt belki [stopnie], C = CRC8
void ParseVisionFrame(const char *frame) {
	float ball_pos = -1.0f;
	float beam_angle = 0.0f;
	uint8_t crc_received = 0;
	int crc_found = 0;

	// Znajdź CRC na końcu
	const char *crc_ptr = strstr(frame, ";C:");
	if (crc_ptr != NULL) {
		crc_received = (uint8_t) strtol(crc_ptr + 3, NULL, 16);
		crc_found = 1;
	}

	// Parsuj pola
	const char *ptr = frame;
	while (*ptr) {
		if (ptr[0] == 'V' && ptr[1] == ':') {
			ball_pos = atof(ptr + 2);
		} else if (ptr[0] == 'B' && ptr[1] == ':') {
			beam_angle = atof(ptr + 2);
		}
		// Przejdź do następnego pola
		while (*ptr && *ptr != ';')
			ptr++;
		if (*ptr == ';')
			ptr++;
	}

	if (crc_found && ball_pos >= 0.0f) {
		int data_len = (crc_ptr != NULL) ? (int) (crc_ptr - frame) : strlen(frame);
		uint8_t crc_calc = CalculateCRC8(frame, data_len);

		if (crc_calc == crc_received) {
			// Dane poprawne - zapisz
			g_vision_ball_pos = ball_pos;
			g_vision_beam_angle = beam_angle;
			g_vision_data_valid = 1;
			g_vision_last_update = HAL_GetTick();
		}
	} else if (ball_pos >= 0.0f) {
		// Brak CRC ale dane wyglądają ok - zaakceptuj (dla testów)
		g_vision_ball_pos = ball_pos;
		g_vision_beam_angle = beam_angle;
		g_vision_data_valid = 1;
		g_vision_last_update = HAL_GetTick();
	}
}

// Przetwarzanie bufora DMA - wywoływane w głównej pętli (polling)
void ProcessDmaRxBuffer(void) {
	// Pobierz aktualną pozycję DMA (ile bajtów pozostało do końca bufora)
	uint16_t dma_tail = DMA_RX_BUFFER_SIZE - __HAL_DMA_GET_COUNTER(&hdma_usart3_rx);

	while (dma_rx_head != dma_tail) {
		uint8_t byte = dma_rx_buffer[dma_rx_head];
		dma_rx_head = (dma_rx_head + 1) % DMA_RX_BUFFER_SIZE;

		if (byte == '\n' || byte == '\r') {
			if (cmd_len > 0) {
				cmd_buffer[cmd_len] = '\0';

				// Sprawdź typ ramki
				if (cmd_buffer[0] == 'V' && cmd_buffer[1] == ':') {
					// Ramka z systemu wizyjnego
					ParseVisionFrame((char*) cmd_buffer);
				} else {
					// Standardowa komenda (S:, P:, I:, D:, itd.)
					memcpy(rx_buffer, cmd_buffer, cmd_len + 1);
					cmd_received = 1;
				}
				cmd_len = 0;
			}
		} else {
			if (cmd_len < 63) {
				cmd_buffer[cmd_len++] = byte;
			}
		}
	}
}

// Callback IDLE line (opcjonalny - dla wykrywania końca transmisji)
void HAL_UARTEx_RxEventCallback(UART_HandleTypeDef *huart, uint16_t Size) {
	if (huart->Instance == USART3) {
	}
}

void HAL_UART_RxCpltCallback(UART_HandleTypeDef *huart) {
}

/**
 * @brief Ustawia kąt serwa w STOPNIACH (środek = 0°)
 * @param degrees: Kąt w stopniach, zakres -90 do +90
 */
void SetServoAngleDeg(float degrees) {
	// Saturacja do fizycznego zakresu serwa
	if (degrees < -90.0f)
		degrees = -90.0f;
	if (degrees > 90.0f)
		degrees = 90.0f;

	// Przeliczenie: degrees -> PWM (1500 ± degrees/90 * 1000)
	uint32_t pulse_length = (uint32_t) (SERVO_PWM_CENTER + (degrees / SERVO_PWM_RANGE) * 1000.0f);

	__HAL_TIM_SET_COMPARE(&htim3, TIM_CHANNEL_1, pulse_length);
}

// Aktualny kąt sprzętowy w stopniach (do slew rate) - NIE static, dostępna z zewnątrz
float g_current_hw_angle_deg = SERVO_CENTER_DEG;

/**
 * @brief Ustawia kąt serwa z slew rate i deadband (w stopniach)
 * @param target_deg: Docelowy kąt w stopniach
 */
void SetServoAngleSmoothDeg(float target_deg) {
	float diff = target_deg - g_current_hw_angle_deg;

	// Deadband - nie aktualizuj przy zbyt małej zmianie
	if (diff > -SERVO_ANGLE_DEADBAND && diff < SERVO_ANGLE_DEADBAND) {
		return;
	}

	// Slew rate limiter
	float max_change = SERVO_SLEW_RATE * (PID_DT_MS / 1000.0f);
	if (diff > max_change) {
		target_deg = g_current_hw_angle_deg + max_change;
	} else if (diff < -max_change) {
		target_deg = g_current_hw_angle_deg - max_change;
	}

	// Saturacja do limitów roboczych
	if (target_deg < SERVO_MIN_DEG)
		target_deg = SERVO_MIN_DEG;
	if (target_deg > SERVO_MAX_DEG)
		target_deg = SERVO_MAX_DEG;

	SetServoAngleDeg(target_deg);
	g_current_hw_angle_deg = target_deg;
}

/* USER CODE END 0 */

/**
 * @brief  The application entry point.
 * @retval int
 */
int main(void) {

	/* MCU Configuration--------------------------------------------------------*/

	/* Reset of all peripherals, Initializes the Flash interface and the Systick. */
	HAL_Init();

	/* USER CODE BEGIN Init */
	HAL_Delay(500); // Czekaj na ustabilizowanie zasilania czujników
	/* USER CODE END Init */

	/* Configure the system clock */
	SystemClock_Config();

	/* Initialize all configured peripherals */
	MX_GPIO_Init();
	MX_DMA_Init();
	MX_ETH_Init();
	MX_USART3_UART_Init();
	MX_USB_OTG_FS_PCD_Init();
	MX_TIM3_Init();
	MX_I2C1_Init();
	MX_ADC1_Init();
	/* USER CODE BEGIN 2 */

	// Initialization moved to StartControlTask
	/* USER CODE END 2 */

	/* USER CODE BEGIN RTOS_MUTEX */
	/* add mutexes, ... */
	/* USER CODE END RTOS_MUTEX */

	/* USER CODE BEGIN RTOS_SEMAPHORES */
	/* add semaphores, ... */
	/* USER CODE END RTOS_SEMAPHORES */

	/* USER CODE BEGIN RTOS_TIMERS */
	/* start timers, add new ones, ... */
	/* USER CODE END RTOS_TIMERS */

	/* USER CODE BEGIN RTOS_QUEUES */
	/* add queues, ... */
	/* USER CODE END RTOS_QUEUES */

	/* Create the thread(s) */
	/* definition and creation of defaultTask */
	osThreadDef(defaultTask, StartDefaultTask, osPriorityNormal, 0, 256);
	defaultTaskHandle = osThreadCreate(osThread(defaultTask), NULL);

	/* definition and creation of ControlTask */
	osThreadDef(ControlTask, StartControlTask, osPriorityHigh, 0, 1024);
	ControlTaskHandle = osThreadCreate(osThread(ControlTask), NULL);

	/* USER CODE BEGIN RTOS_THREADS */
	/* add threads, ... */
	/* USER CODE END RTOS_THREADS */

	/* Start scheduler */
	osKernelStart();

	/* We should never get here as control is now taken by the scheduler */

	/* Infinite loop */
	/* USER CODE BEGIN WHILE */
	/* USER CODE BEGIN WHILE */
	while (1) {
		/* USER CODE END WHILE */

		/* USER CODE BEGIN 3 */
	}
	/* USER CODE END 3 */
}

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
/* USER CODE BEGIN Header_StartDefaultTask */
/**
 * @brief  Function implementing the defaultTask thread.
 * @param  argument: Not used
 * @retval None
 */
/* USER CODE END Header_StartDefaultTask */
void StartDefaultTask(void const *argument) {
	/* USER CODE BEGIN 5 */
	// Poczekaj na inicjalizację DMA w ControlTask (min 2.2s)
	osDelay(3000);

	HAL_UART_Transmit(&huart3, (uint8_t*) "[DEFAULT] Task started, DMA polling active\r\n", 44, 100);

	/* Infinite loop */
	for (;;) {
		// --- PRZETWARZANIE BUFORA DMA (polling) ---
		// Przetwarzamy tutaj aby komendy (S:, P:, I:, D:) były obsługiwane
		ProcessDmaRxBuffer();

		// Obsługa komend UART (przeniesione z ControlTask)
		if (cmd_received) {
			if (rx_buffer[0] == 'S' && rx_buffer[1] == ':') {
				g_setpoint = atof((char*) &rx_buffer[2]); // S:Setpoint
				if (g_setpoint < 0.0f)
					g_setpoint = 0.0f;
				if (g_setpoint > 250.0f)
					g_setpoint = 250.0f;
			} else if (rx_buffer[0] == 'P' && rx_buffer[1] == ':') {
				g_Kp = atof((char*) &rx_buffer[2]);
			} else if (rx_buffer[0] == 'I' && rx_buffer[1] == ':') {
				g_Ki = atof((char*) &rx_buffer[2]);
			} else if (rx_buffer[0] == 'D' && rx_buffer[1] == ':') {
				g_Kd = atof((char*) &rx_buffer[2]);
			} else if (rx_buffer[0] == 'L' && rx_buffer[1] == '1' && rx_buffer[2] == ':') {
				// LQR K1 gain (pozycja)
				g_K1 = atof((char*) &rx_buffer[3]);
				LQR_UpdateGains(&g_lqr_ctrl, g_K1, g_K2, g_K3);
				sprintf(msg, "LQR K1: %.2f\r\n", g_K1);
				HAL_UART_Transmit(&huart3, (uint8_t*) msg, strlen(msg), 100);
			} else if (rx_buffer[0] == 'L' && rx_buffer[1] == '2' && rx_buffer[2] == ':') {
				// LQR K2 gain (prędkość)
				g_K2 = atof((char*) &rx_buffer[3]);
				LQR_UpdateGains(&g_lqr_ctrl, g_K1, g_K2, g_K3);
				sprintf(msg, "LQR K2: %.2f\r\n", g_K2);
				HAL_UART_Transmit(&huart3, (uint8_t*) msg, strlen(msg), 100);
			} else if (rx_buffer[0] == 'L' && rx_buffer[1] == '3' && rx_buffer[2] == ':') {
				// LQR K3 gain (kąt belki)
				g_K3 = atof((char*) &rx_buffer[3]);
				LQR_UpdateGains(&g_lqr_ctrl, g_K1, g_K2, g_K3);
				sprintf(msg, "LQR K3: %.2f\r\n", g_K3);
				HAL_UART_Transmit(&huart3, (uint8_t*) msg, strlen(msg), 100);
			} else if (rx_buffer[0] == 'X' && rx_buffer[1] == ':') {
				// Przełączanie trybu regulatora: 0 = Custom PID, 1 = LQR
				g_pid_mode = (uint8_t) atoi((char*) &rx_buffer[2]);
				const char *mode_name = (g_pid_mode == 0) ? "CUSTOM PID" : "LQR";
				sprintf(msg, "CONTROLLER MODE: %s\r\n", mode_name);
				HAL_UART_Transmit(&huart3, (uint8_t*) msg, strlen(msg), 100);
			}
			// Komendy Kalibracji
			// Format: "CAL0:50.0,0.0" -> Punkt 0: Surowy=50.0, Rzeczywisty=0.0
			else if (strncmp((char*) rx_buffer, "CAL:RESET", 9) == 0) {
				Calibration_Init();
				sprintf(msg, "[CAL] RESET DONE. Waiting for points...\r\n");
				HAL_UART_Transmit(&huart3, (uint8_t*) msg, strlen(msg), 100);
			} else if (rx_buffer[0] == 'C' && rx_buffer[1] == 'A' && rx_buffer[2] == 'L') {
				int cal_idx = rx_buffer[3] - '0'; // Indeks punktu
				if (cal_idx >= 0 && cal_idx < 5) {
					char *comma = strchr((char*) &rx_buffer[5], ',');
					if (comma != NULL) {
						*comma = '\0';
						float raw_val = atof((char*) &rx_buffer[5]);
						float actual_val = atof(comma + 1);

						// Aktualizacja w bibliotece kalibracyjnej
						Calibration_UpdatePoint(cal_idx, raw_val, actual_val);

						// Sprawdzenie czy mamy komplet punktów
						if (Calibration_IsReady()) {
							sprintf(msg, "[CAL] ✅ All points received! System READY!\r\n");
							HAL_UART_Transmit(&huart3, (uint8_t*) msg, strlen(msg), 100);
						} else {
							// Potwierdzenie przyjęcia punktu
							int r_i = (int) raw_val;
							int r_d = (int) ((raw_val - r_i) * 10);
							int a_i = (int) actual_val;
							int a_d = (int) ((actual_val - a_i) * 10);

							sprintf(msg, "[CAL] Point %d: RAW=%d.%d -> POS=%d.%d (%d/5)\r\n", cal_idx, r_i, abs(r_d),
									a_i, abs(a_d), __builtin_popcount(Calibration_GetReceivedPointsMask()));
							HAL_UART_Transmit(&huart3, (uint8_t*) msg, strlen(msg), 100);
						}
					}
				}
			} else if (rx_buffer[0] == 'M' && rx_buffer[1] == ':') {
				// M:0 -> GUI, M:1 -> Potencjometr, M:2 -> Sinus
				control_mode = (uint8_t) atoi((char*) &rx_buffer[2]);
				const char *mode_names[] = { "GUI", "ANALOG", "SINUS" };
				if (control_mode <= 2) {
					sprintf(msg, "MODE: %s\r\n", mode_names[control_mode]);
					HAL_UART_Transmit(&huart3, (uint8_t*) msg, strlen(msg), 100);
				}
			} else if (rx_buffer[0] == 'R' && rx_buffer[1] == ':') {
				// R:0 -> Stop regulatora, R:1 -> Start regulatora
				g_regulator_enabled = (uint8_t) atoi((char*) &rx_buffer[2]);
				sprintf(msg, "REG: %s\r\n", g_regulator_enabled ? "ON" : "OFF");
				HAL_UART_Transmit(&huart3, (uint8_t*) msg, strlen(msg), 100);

				// Jeśli wyłączony - ustaw serwo na środek
				if (!g_regulator_enabled) {
					// SetServoAngle(SERVO_CENTER); // USUNIĘTE: Teraz używamy g_manual_servo_angle
				}
			} else if (rx_buffer[0] == 'T' && rx_buffer[1] == ':') {
				// T:xx -> Zmiana okresu próbkowania (ms)
				uint32_t new_dt = (uint32_t) atoi((char*) &rx_buffer[2]);
				if (new_dt >= 5 && new_dt <= 500) {
					g_pid_dt_ms = new_dt;
					// g_pid_needs_reinit = 1; // Removed
					sprintf(msg, "DT: %lu ms (%.1f Hz)\r\n", g_pid_dt_ms, 1000.0f / g_pid_dt_ms);
					HAL_UART_Transmit(&huart3, (uint8_t*) msg, strlen(msg), 100);
				} else {
					sprintf(msg, "DT ERR: must be 5-500ms\r\n");
					HAL_UART_Transmit(&huart3, (uint8_t*) msg, strlen(msg), 100);
				}
			} else if (rx_buffer[0] == 'L' && rx_buffer[1] == ':') {
				// L:Angle -> Ustawienie kąta w trybie otwartym (gdy R:0)
				// Teraz akceptujemy kąt w stopniach (-30 do +30)
				g_manual_servo_angle_deg = atof((char*) &rx_buffer[2]);
				if (g_manual_servo_angle_deg < SERVO_MIN_DEG)
					g_manual_servo_angle_deg = SERVO_MIN_DEG;
				if (g_manual_servo_angle_deg > SERVO_MAX_DEG)
					g_manual_servo_angle_deg = SERVO_MAX_DEG;

				// NATYCHMIAST ustaw serwo (bez czekania na główną pętlę)
				SetServoAngleDeg(g_manual_servo_angle_deg);

				// Send ACK for debugging
				sprintf(msg, "L-ACK: %.2f deg\r\n", g_manual_servo_angle_deg);
				HAL_UART_Transmit(&huart3, (uint8_t*) msg, strlen(msg), 10);
			} else if (strncmp((char*) rx_buffer, "TEST:START", 10) == 0) {
				g_test_index = 0;
				g_test_running = 1;
				g_regulator_enabled = 0; // Wyłącz regulator PID
				sprintf(msg, "[TEST] STARTED. Len=%d\r\n", (int) SEQUENCE_LEN);
				HAL_UART_Transmit(&huart3, (uint8_t*) msg, strlen(msg), 100);
			} else if (strncmp((char*) rx_buffer, "TEST:STOP", 9) == 0) {
				g_test_running = 0;
				SetServoAngleDeg(SERVO_CENTER);
				sprintf(msg, "[TEST] STOPPED.\r\n");
				HAL_UART_Transmit(&huart3, (uint8_t*) msg, strlen(msg), 100);
			}

			cmd_received = 0;
		}

		// Aktualizacja LEDów błędu (niekrytyczne czasowo)
		UpdateErrorLEDs_5LED(g_current_error);

		osDelay(5); // 5ms - wystarczająco szybko dla UART
	}
	/* USER CODE END 5 */
}
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

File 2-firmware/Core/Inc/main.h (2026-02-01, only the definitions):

#define LED_ERR_1_Pin GPIO_PIN_2
#define LED_ERR_1_GPIO_Port GPIOE
#define LED_ERR_2_Pin GPIO_PIN_3
#define LED_ERR_2_GPIO_Port GPIOE
#define LED_ERR_3_Pin GPIO_PIN_4
#define LED_ERR_3_GPIO_Port GPIOE
#define LED_ERR_4_Pin GPIO_PIN_5
#define LED_ERR_4_GPIO_Port GPIOE
#define LED_ERR_5_Pin GPIO_PIN_6
#define LED_ERR_5_GPIO_Port GPIOE
#define USER_Btn_Pin GPIO_PIN_13
#define USER_Btn_GPIO_Port GPIOC
#define MCO_Pin GPIO_PIN_0
#define MCO_GPIO_Port GPIOH
#define RMII_MDC_Pin GPIO_PIN_1
#define RMII_MDC_GPIO_Port GPIOC
#define RMII_REF_CLK_Pin GPIO_PIN_1
#define RMII_REF_CLK_GPIO_Port GPIOA
#define RMII_MDIO_Pin GPIO_PIN_2
#define RMII_MDIO_GPIO_Port GPIOA
#define RMII_CRS_DV_Pin GPIO_PIN_7
#define RMII_CRS_DV_GPIO_Port GPIOA
#define RMII_RXD0_Pin GPIO_PIN_4
#define RMII_RXD0_GPIO_Port GPIOC
#define RMII_RXD1_Pin GPIO_PIN_5
#define RMII_RXD1_GPIO_Port GPIOC
#define LD1_Pin GPIO_PIN_0
#define LD1_GPIO_Port GPIOB
#define CALIB_START_BTN_Pin GPIO_PIN_1
#define CALIB_START_BTN_GPIO_Port GPIOB
#define CALIB_MID_BTN_Pin GPIO_PIN_2
#define CALIB_MID_BTN_GPIO_Port GPIOB
#define RMII_TXD1_Pin GPIO_PIN_13
#define RMII_TXD1_GPIO_Port GPIOB
#define LD3_Pin GPIO_PIN_14
#define LD3_GPIO_Port GPIOB
#define STLK_RX_Pin GPIO_PIN_8
#define STLK_RX_GPIO_Port GPIOD
#define STLK_TX_Pin GPIO_PIN_9
#define STLK_TX_GPIO_Port GPIOD
#define USB_PowerSwitchOn_Pin GPIO_PIN_6
#define USB_PowerSwitchOn_GPIO_Port GPIOG
#define USB_OverCurrent_Pin GPIO_PIN_7
#define USB_OverCurrent_GPIO_Port GPIOG
#define USB_SOF_Pin GPIO_PIN_8
#define USB_SOF_GPIO_Port GPIOA
#define USB_VBUS_Pin GPIO_PIN_9
#define USB_VBUS_GPIO_Port GPIOA
#define USB_ID_Pin GPIO_PIN_10
#define USB_ID_GPIO_Port GPIOA
#define USB_DM_Pin GPIO_PIN_11
#define USB_DM_GPIO_Port GPIOA
#define USB_DP_Pin GPIO_PIN_12
#define USB_DP_GPIO_Port GPIOA
#define TMS_Pin GPIO_PIN_13
#define TMS_GPIO_Port GPIOA
#define TCK_Pin GPIO_PIN_14
#define TCK_GPIO_Port GPIOA
#define RMII_TX_EN_Pin GPIO_PIN_11
#define RMII_TX_EN_GPIO_Port GPIOG
#define RMII_TXD0_Pin GPIO_PIN_13
#define RMII_TXD0_GPIO_Port GPIOG
#define SWO_Pin GPIO_PIN_3
#define SWO_GPIO_Port GPIOB
#define CALIB_END_BTN_Pin GPIO_PIN_4
#define CALIB_END_BTN_GPIO_Port GPIOB
#define LD2_Pin GPIO_PIN_7
#define LD2_GPIO_Port GPIOB
#define PID_DT_MS          30
#define SETPOINT_DEFAULT   125.0f
#define BALL_RADIUS        20
#define AVG_ERR_SAMPLES    35
#define SENSOR_TEST_MODE   0
#define USE_CALIBRATION    1
#define SERVO_CENTER_DEG   0.0f      // Środek = poziomo
#define SERVO_MIN_DEG     -30.0f     // Limit lewy (stare 70)
#define SERVO_MAX_DEG      30.0f     // Limit prawy (stare 130)
#define SERVO_SLEW_RATE    200.0f    // Stopni na sekundę (było 1000 jednostek/s)
#define SERVO_ANGLE_DEADBAND 0.1f    // Stopnie
#define SERVO_SMOOTHING_SIZE 1
#define SERVO_PWM_MIN      500       // 500μs = -90°
#define SERVO_PWM_CENTER   1500      // 1500μs = 0°
#define SERVO_PWM_MAX      2500      // 2500μs = +90°
#define SERVO_PWM_RANGE    90.0f     // ±90° zakres fizyczny serwa
#define SERVO_CENTER       SERVO_CENTER_DEG   // 0° (było 100)
#define SERVO_MIN_LIMIT    SERVO_MIN_DEG      // -30° (było 70)  
#define SERVO_MAX_LIMIT    SERVO_MAX_DEG      // +30° (było 130)
#define D_DEADBAND         0.1f
#define D_FILTER_ALPHA     0.5f
#define LED_ERR_PORT      GPIOE
#define LED_ERR_1_Pin     GPIO_PIN_2
#define LED_ERR_2_Pin     GPIO_PIN_3
#define LED_ERR_3_Pin     GPIO_PIN_4
#define LED_ERR_4_Pin     GPIO_PIN_5
#define LED_ERR_5_Pin     GPIO_PIN_6
#define LED_ERR_6_Pin     GPIO_PIN_7
#define LED_ERR_7_Pin     GPIO_PIN_8
#define LED_ERR_8_Pin     GPIO_PIN_9
#define LED_ERR_9_Pin     GPIO_PIN_10

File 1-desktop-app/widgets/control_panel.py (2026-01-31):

import os
import json
from PySide6.QtWidgets import QWidget, QVBoxLayout, QLabel, QSlider, QHBoxLayout, QPushButton, QButtonGroup, QGridLayout, QFrame, QRadioButton, QComboBox, QLineEdit, QMessageBox, QInputDialog, QDoubleSpinBox
from PySide6.QtCore import Qt, Signal, QTimer
from widgets.beam_visualizer import BeamVisualizer


class SliderControl(QWidget):
    value_changed = Signal(float)
    value_committed = Signal(float)

    def __init__(self, label, min_val, max_val, step, init_val, unit=""):
        super().__init__()
        self.step = step
        self.unit = unit
        self.factor = 1.0 / step if step < 1 else 1.0

        layout = QHBoxLayout(self)
        layout.setContentsMargins(5, 5, 5, 5)
        layout.setSpacing(10)

        self.lbl_name = QLabel(label)
        self.lbl_name.setStyleSheet("font-weight: bold; color: #94a3b8;")
        self.lbl_name.setFixedWidth(30)

        self.lbl_val = QLabel(f"{init_val} {unit}")
        self.lbl_val.setFixedWidth(50)
        self.lbl_val.setAlignment(Qt.AlignRight | Qt.AlignVCenter)
        self.lbl_val.setStyleSheet("color: #3b82f6; font-family: monospace; font-weight: bold;")

        self.slider = QSlider(Qt.Horizontal)
        self.slider.setMinimum(int(min_val * self.factor))
        self.slider.setMaximum(int(max_val * self.factor))
        self.slider.setValue(int(init_val * self.factor))

        self.slider.valueChanged.connect(self._on_change)
        self.slider.sliderReleased.connect(self._on_release)

        layout.addWidget(self.lbl_name)
        layout.addWidget(self.slider)
        layout.addWidget(self.lbl_val)

        self.setObjectName("sliderContainer")
        self.setStyleSheet(
            """
            QWidget#sliderContainer {
                background-color: rgba(255, 255, 255, 0.03);
                border: 1px solid rgba(255, 255, 255, 0.08);
                border-radius: 6px;
            }
        """
        )

    def _on_change(self, val):
        real_val = val / self.factor
        if self.step < 1:
            fmt = "{:.4f}" if self.step < 0.001 else "{:.2f}"
        else:
            fmt = "{:.0f}"
        self.lbl_val.setText(f"{fmt.format(real_val)} {self.unit}")
        self.value_changed.emit(real_val)

    def _on_release(self):
        real_val = self.slider.value() / self.factor
        self.value_committed.emit(real_val)

    def set_value(self, val):
        self.slider.setValue(int(val * self.factor))


class ControlPanel(QWidget):
    pid_update = Signal(float, float, float)
    kp_update = Signal(float)
    ki_update = Signal(float)
    kd_update = Signal(float)
    setpoint_update = Signal(float)
    calibration_update = Signal(int, float, float)
    mode_update = Signal(int)
    pid_mode_update = Signal(int)
    # LQR signals
    lqr_k1_update = Signal(float)
    lqr_k2_update = Signal(float)
    lqr_k3_update = Signal(float)

    def __init__(self):
        super().__init__()

        self.layout = QVBoxLayout(self)
        self.layout.setContentsMargins(5, 5, 5, 5)
        self.layout.setSpacing(8)

        self.setObjectName("panel")
        self.setProperty("class", "card")

        source_frame = QFrame()
        source_frame.setStyleSheet("background-color: rgba(255,255,255,0.05); border-radius: 4px; padding: 2px;")
        source_layout = QHBoxLayout(source_frame)
        source_layout.setContentsMargins(5, 2, 5, 2)

        lbl_source = QLabel("Źródło:")
        lbl_source.setStyleSheet("font-weight: bold; color: #ccc;")

        self.rb_gui = QRadioButton("GUI (Suwak)")
        self.rb_gui.setChecked(True)
        self.rb_analog = QRadioButton("Potencjometr")
        self.rb_sinus = QRadioButton("Sinus")

        self.mode_group = QButtonGroup(self)
        self.mode_group.addButton(self.rb_gui, 0)
        self.mode_group.addButton(self.rb_analog, 1)
        self.mode_group.addButton(self.rb_sinus, 2)
        self.mode_group.idClicked.connect(self.mode_update.emit)

        source_layout.addWidget(lbl_source)
        source_layout.addStretch()
        source_layout.addWidget(self.rb_gui)
        source_layout.addWidget(self.rb_analog)
        source_layout.addWidget(self.rb_sinus)

        self.layout.addWidget(source_frame)

        self.viz = BeamVisualizer()
        self.viz.setpoint_changed.connect(self._on_viz_setpoint)
        self.layout.addWidget(self.viz)

        self.cal_points = [None] * 5
        self.cal_targets = [0, 62.5, 125, 187.5, 250]
        self.cal_btns = []

        # === Controller Mode Selection ===
        controller_mode_group = QFrame()
        controller_mode_group.setObjectName("controllerModeGroup")
        controller_mode_group.setStyleSheet("#controllerModeGroup { background-color: #1a1f2e; border: 1px solid #334155; border-radius: 8px; }")
        controller_mode_layout = QVBoxLayout(controller_mode_group)
        controller_mode_layout.setContentsMargins(5, 5, 5, 5)
        controller_mode_layout.setSpacing(5)

        controller_mode_label = QLabel("TRYB REGULATORA")
        controller_mode_label.setStyleSheet("color: #a78bfa; font-weight: bold; font-size: 11px;")
        controller_mode_layout.addWidget(controller_mode_label)

        controller_mode_buttons = QHBoxLayout()
        self.rb_custom_pid = QRadioButton("Custom PID")
        self.rb_lqr = QRadioButton("LQR")
        self.rb_custom_pid.setChecked(True)

        self.controller_mode_group = QButtonGroup(self)
        self.controller_mode_group.addButton(self.rb_custom_pid, 0)
        self.controller_mode_group.addButton(self.rb_lqr, 1)
        self.controller_mode_group.idClicked.connect(self._on_controller_mode_change)

        controller_mode_buttons.addWidget(self.rb_custom_pid)
        controller_mode_buttons.addWidget(self.rb_lqr)
        controller_mode_layout.addLayout(controller_mode_buttons)

        self.layout.addWidget(controller_mode_group)

        # === PID Parameters ===
        self.pid_group = QFrame()
        self.pid_group.setObjectName("pidGroup")
        self.pid_group.setStyleSheet("#pidGroup { background-color: #1a1f2e; border: 1px solid #334155; border-radius: 8px; }")
        pid_layout = QVBoxLayout(self.pid_group)
        pid_layout.setContentsMargins(5, 5, 5, 5)
        pid_layout.setSpacing(5)

        pid_header = QHBoxLayout()
        pid_label = QLabel("PARAMETRY REGULATORA (PID)")
        pid_label.setStyleSheet("color: #3b82f6; font-weight: bold; font-size: 11px;")

        pid_header.addWidget(pid_label)
        pid_header.addStretch()

        pid_layout.addLayout(pid_header)

        self.sli_kp = SliderControl("Kp", 0.0, 2.0, 0.01, 0.44)
        self.sli_ki = SliderControl("Ki", 0.0, 0.01, 0.0001, 0.0053)
        self.sli_kd = SliderControl("Kd", 0.0, 10.0, 0.1, 5.0)

        self.sli_kp.value_committed.connect(self._on_kp_change)
        self.sli_ki.value_committed.connect(self._on_ki_change)
        self.sli_kd.value_committed.connect(self._on_kd_change)
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

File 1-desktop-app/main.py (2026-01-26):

import sys
import os
import traceback
from PySide6.QtGui import QFont
from PySide6.QtWidgets import QApplication
from app import MainWindow


def main():
    try:
        app = QApplication(sys.argv)
        app.setFont(QFont("Segoe UI", 10))

        style_path = os.path.join(os.path.dirname(__file__), "styles", "dark_theme.qss")
        if os.path.exists(style_path):
            with open(style_path, "r") as f:
                app.setStyleSheet(f.read())
        else:
            print("Warning: Stylesheet not found.")

        window = MainWindow()
        window.showMaximized()

        sys.exit(app.exec())
    except Exception as e:
        print(f"\nCRITICAL ERROR: {e}")
        traceback.print_exc()
        input("Press Enter to exit...")


if __name__ == "__main__":
    main()

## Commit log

2026-01-13 sinus jako zrodlo setpointu
    [przebieg.csv]
2026-01-13 przelacznik pomiedzy pid cmsis a pochodna z pomiaru
2026-01-13 fajnie dziala pid cmsis i nasz i fajne nastawy dobrane
2026-01-13 FINAL FINAL FINAL
    [test.csv]
2026-01-15 ekran 2 w apce desktop
    [nagranie_20260114_133218.csv]
2026-01-16 read me i update odczytu czujnika
    [Assembly1.0005.iam, Assembly1.iam, Grove - Time of Flight Distance Sensor(VL53L0X).brd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]
2026-01-17 proby naprawienia blokowania sie serwa
    [nagranie_20260117_203710.csv, nagranie_20260117_203715.csv, nagranie_20260117_203740.csv]
2026-01-18 fix: w duzej czesci naprawiono blokowanie sie serwa, dodanie slew rate dla serwa
    [main.c, main.h]
2026-01-18 identyfikacje 2
    [identyfikacja-10.csv, identyfikacja-111.csv, identyfikacja-112.csv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]
2026-01-19 dane: zadany skok
    [odp-na-skok.csv]
2026-01-26 feat: system wizyjny dziala okej
    [identyfikacja-1.csv, identyfikacja-2.csv, identyfikacja-3.csv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]
2026-01-27 polaczenie systemu wizyjnego z stm, reorganizacja struktury folderów projektu
    [nagranie_20260127_213103.csv]
2026-01-28 lqr wektor stanu 2 elementowy
    [identyfikacja-10.csv, identyfikacja-111.csv, identyfikacja-112.csv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]
2026-01-28 lqr dziala bardzo fajnie
    [prbs.csv, prbs2.csv, wychylenie-109.csv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]
2026-01-31 reorganizacja struktury folderow
    [identyfikacja-10.csv, identyfikacja-111.csv, identyfikacja-112.csv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]
2026-02-01 Add files via upload
    schemat w simulinku, liczenie modelu dla skoku i parametrów regulatora oraz proba aprbs do poprawki
2026-02-01 Add files via upload
    do skokowej
    [wychylenie-109.csv, wychylenie-112.csv, wychylenie-115.csv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]
2026-03-20 Aktualizacja skryptów identyfikacji i parametrów regulatora, dodanie wykresów PDF
2026-03-26 posprzatane pliki 2
    [Assembly1.0005.iam, Assembly1.iam, Grove - Time of Flight Distance Sensor(VL53L0X).brd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]

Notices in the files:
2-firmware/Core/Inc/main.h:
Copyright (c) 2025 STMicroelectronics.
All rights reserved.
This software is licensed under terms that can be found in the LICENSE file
